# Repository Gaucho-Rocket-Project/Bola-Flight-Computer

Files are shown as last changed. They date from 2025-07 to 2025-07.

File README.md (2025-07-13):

# Bola Flight Computer  
*Lead Engineer: Ethan Scanlon & Jacob Ismael*  

> **Status:** Hardware‐only repository – PCB design files, footprints and production data for the first-generation Bola flight computer. Firmware lives in the separate [`bola`](https://github.com/Gaucho-Rocket-Project/bola) repo.

## Overview
Bola is an open-source, miniature flight computer for experimental rockets.  
It is built around an **ESP32-S3** microcontroller and pairs a 9-DoF IMU with a high-resolution barometer to provide real-time state estimation, data-logging and telemetry in a single, compact PCB.  

The hardware in this repository powers the Gaucho Rocket Project’s “Bola” launch vehicle and is released to help other student teams accelerate their avionics development.

## Key Features
| Sub-system | Parts/Notes |
|---|---|
| MCU | Espressif **ESP32-S3** module, 240 MHz dual-core, Wi-Fi & Bluetooth LE|
| Inertial sensing | **ICM-20948** 9-axis IMU (gyro + accel + mag) |
| Altimetry | **BMP581** absolute barometer (32-bit FIFO, 5 Pa RMS) |
| Power | 2-stage regulation: **LD1117-5 V** & **SPX3819-3 V3** LDOs |
| Pyro outputs | Low-side MOSFETs (**DMN3023L-7**) for ejection charges |
| User feedback | JST-XH debug header |
| Connectors | **XT30UPB** main supply; screw terminals for igniters |
| Form factor | 4-layer, 50 × 80 mm PCB < 15 g bare |

## Schematic
Schematic

## PCB Layout
pcb

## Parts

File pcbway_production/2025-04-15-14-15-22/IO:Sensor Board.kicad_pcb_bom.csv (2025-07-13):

Designator | Quantity | Value | Footprint | Package | MPN | DNP | Mount_Type | Description | LCSC | Comment | MF | DESCRIPTION | PRICE | Check_prices | Price | PARTREV | SnapEDA_Link | MP | Availability | AVAILABILITY | Description_1 | SUPPLIER_PART_NUMBER | VALUE | SUPPLIER | FOOTPRINT | MANUFACTURER_PART_NUMBER | STANDARD | MANUFACTURER | MAXIMUM_PACKAGE_HEIGHT
C1, C11, C12, C13, C2, C3, C4, C5, C6 | 9 | 0.1uF | C_0805_2012Metric_Pad1.18x1.45mm_HandSolder |  |  |  | smt | Unpolarized capacitor | C28233
C10, C14, C7, C8 | 4 | 10uF | C_0805_2012Metric_Pad1.18x1.45mm_HandSolder |  |  |  | smt | Unpolarized capacitor | C28233
C15, C9 | 2 | 100uF | C_0805_2012Metric_Pad1.18x1.45mm_HandSolder |  |  |  | smt | Unpolarized capacitor | C28233
J1, J2, J5 | 3 | B3B-XH-A | CONN_B3B-XH-A_JST |  |  |  | tht
J3 | 1 | B6B-XH-A | JST_XH_B6B-XH-A_1x06_P2.50mm_Vertical |  |  |  | tht |  | C144397
J4 | 1 | B2B-XH-A | CONN_B2B-XH-A_JST |  |  |  | tht |  | C158012
JP1, JP2, JP3 | 3 | Jumper_2_Open | SolderJumper-2_P1.3mm_Open_RoundedPad1.0x1.5mm |  |  |  | tht | Jumper, 2-pole, open
P1, P2, P3 | 3 | 282837-2 | CUI_TB002-500-02BE | None |  |  | tht |  |  | 282837-2 | TE Connectivity | TERMINAL BLOCK 3.5MM 2POS PCB | 0.28 USD | https://www.snapeda.com/parts/282837-2/TE+Connectivity+AMP+Connectors/view-part/?ref=eda | None | G3 | https://www.snapeda.com/parts/282837-2/TE+Connectivity+AMP+Connectors/view-part/?ref=snap | 282837-2 | In Stock | Good | Terminal Block Connector Wire Receptacle 2 5.08 mm 30-16 AWG Green 13.5 A 250 V | TE Connectivity 282837-2
Q1, Q2, Q3 | 3 | DMN3023L-7 | SOT96P240X100-3N | None |  |  | smt |  |  |  | Diodes Incorporated | MOSFET N-CH 30V 6.2A SOT23 |  | https://www.snapeda.com/parts/DMN3023L7/Diodes+Inc./view-part/?ref=eda | None |  | https://www.snapeda.com/parts/DMN3023L7/Diodes+Inc./view-part/?ref=snap | DMN3023L7 | In Stock |  | N-Channel 30 V 6.2A (Ta) 900mW (Ta) Surface Mount SOT-23-3 | DMN3023L-7DICT-ND | DMN3023L-7 | Digikey | SOT23 | DMN3023L-7
R1, R3, R5 | 3 | 1k | R_0805_2012Metric_Pad1.20x1.40mm_HandSolder | None |  |  | smt |  |  | 8-2176243-2 | TE Connectivity |  |  | https://www.snapeda.com/parts/8-2176243-2/TE+Connectivity+AMP+Connectors/view-part/?ref=eda | None |  | https://www.snapeda.com/parts/8-2176243-2/TE+Connectivity+AMP+Connectors/view-part/?ref=snap | 8-2176243-2 | In Stock |  | CRGS0603 Anti-Surge Resistor 5% 5M6
R2, R4, R6 | 3 | 470 | R_0805_2012Metric_Pad1.20x1.40mm_HandSolder | None |  |  | smt |  |  | 8-2176243-2 | TE Connectivity |  |  | https://www.snapeda.com/parts/8-2176243-2/TE+Connectivity+AMP+Connectors/view-part/?ref=eda | None |  | https://www.snapeda.com/parts/8-2176243-2/TE+Connectivity+AMP+Connectors/view-part/?ref=snap | 8-2176243-2 | In Stock |  | CRGS0603 Anti-Surge Resistor 5% 5M6
U1 | 1 | BMP581 | QFN10_BMP581_BOS |  |  |  | smt |  | C5362283
U10, U8 | 2 | XT30UPB-M | XT30UPB-M | None |  |  | tht |  |  |  | amass |  |  | https://www.snapeda.com/parts/XT30UPB-M/AMASS/view-part/?ref=eda | None |  | https://www.snapeda.com/parts/XT30UPB-M/AMASS/view-part/?ref=snap | XT30UPB-M | Not in stock |  | Socket; DC supply; XT30; male; PIN: 2; on PCBs; THT; yellow; 15A; 500V
U2 | 1 | DEVKIT_V1_ESP32-WROOM-32 | MODULE_DEVKIT_V1_ESP32-WROOM-32 | Package |  |  | tht |  |  |  | Espressif Systems |  |  | https://www.snapeda.com/parts/DEVKIT%20V1%20ESP32-WROOM-32/Espressif+Systems/view-part/?ref=eda | None | N/A | https://www.snapeda.com/parts/DEVKIT%20V1%20ESP32-WROOM-32/Espressif+Systems/view-part/?ref=snap | DEVKIT V1 ESP32-WROOM-32 | Not in stock |  | WROOM-32 Development Board ESP32 ESP-32S WiFi Bluetooth Dev Module |  |  |  |  |  | Manufacturer Recommendations | Espressif Systems
U3 | 1 | TPS79333-EP | SOT-23-5 |  |  |  | smt | 200mA UltraLow-Noise, High-Precision, Fast RF, Low Drop-out Voltage Regulator, Fixed Output 3.3V, SOT-23 | C9840
U4 | 1 | ICM-20948 | QFN24_3X3X0P9_IVS |  |  |  | smt |  | C726001
U5 | 1 | TPS79318-EP | SOT-23-5 |  |  |  | smt | 200mA UltraLow-Noise, High-Precision, Fast RF, Low Drop-out Voltage Regulator, Fixed Output 1.8V, SOT-23 | C7102
U7, U9 | 2 | LD1117S50CTR | LD1117S50CTR | SOT-223 STMicroelectronics |  |  | smt |  |  |  | STMicroelectronics |  |  | https://www.snapeda.com/parts/LD1117S50CTR/STMicroelectronics/view-part/?ref=eda | None | 37 | https://www.snapeda.com/parts/LD1117S50CTR/STMicroelectronics/view-part/?ref=snap | LD1117S50CTR | In Stock |  | Linear Voltage Regulator IC Positive Fixed 1 Output 800mA SOT-223 |  |  |  |  |  | IPC 7351B | STMicroelectronics | 1.8 mm

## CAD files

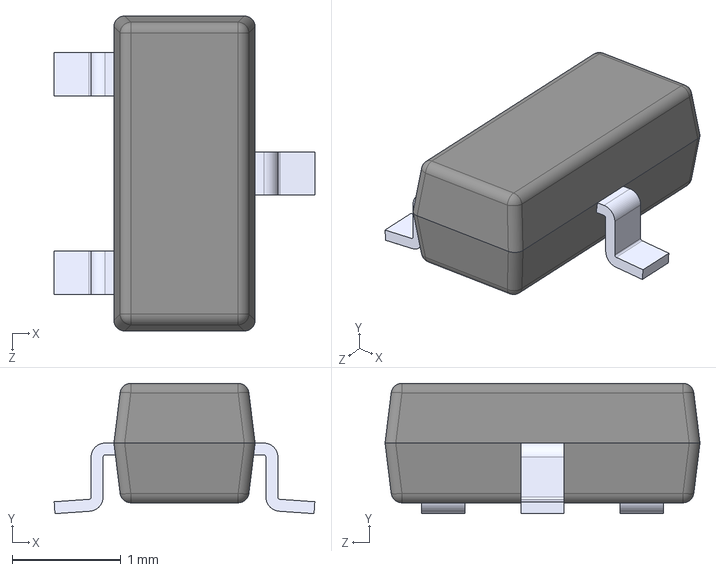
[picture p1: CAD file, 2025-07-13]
DMN3023L-7/DMN3023L-7.step
2.40 x 1.20 x 2.90 mm

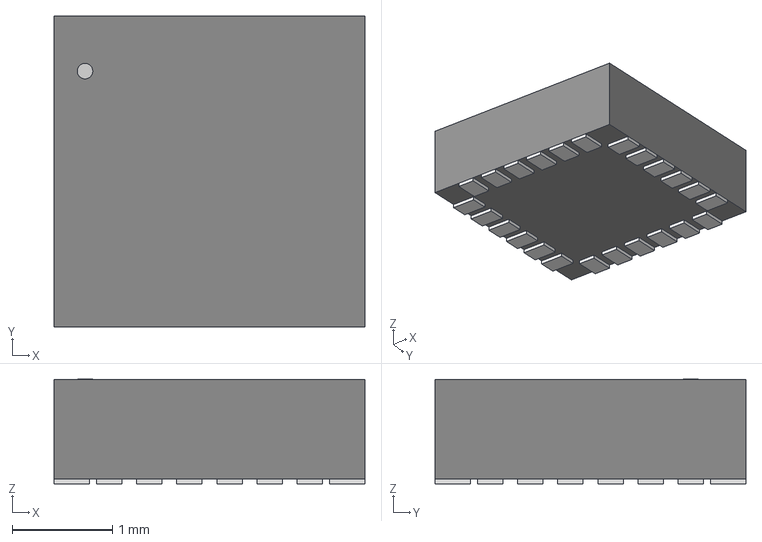
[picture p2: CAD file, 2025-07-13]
ICM-20948/QFN24_3X3X0P9_IVS.step
3.10 x 3.10 x 1.04 mm

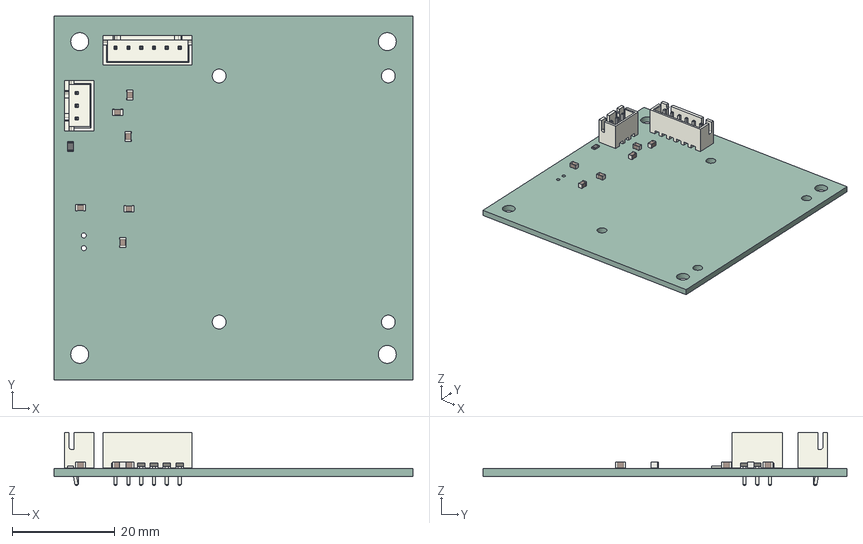
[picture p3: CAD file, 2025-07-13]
IO:Sensor Board.step
70.0 x 71.0 x 10.4 mm
JST_B3B_XH_A
C_0805_2012Metric x 6
R_0805_2012Metric
JST_B6B_XH_A
IO:Sensor Board_PCB

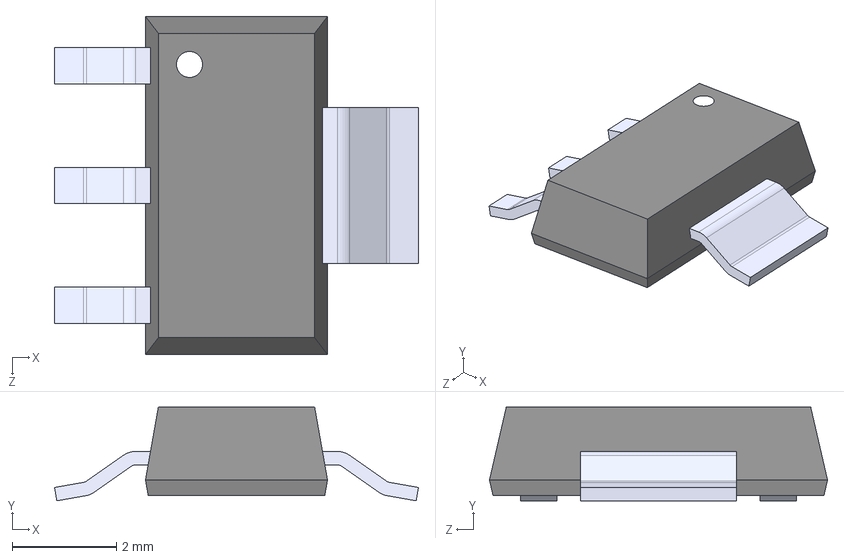
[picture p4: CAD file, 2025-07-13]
LD1117S50CTR/LD1117S50CTR.step
7.00 x 1.80 x 6.50 mm

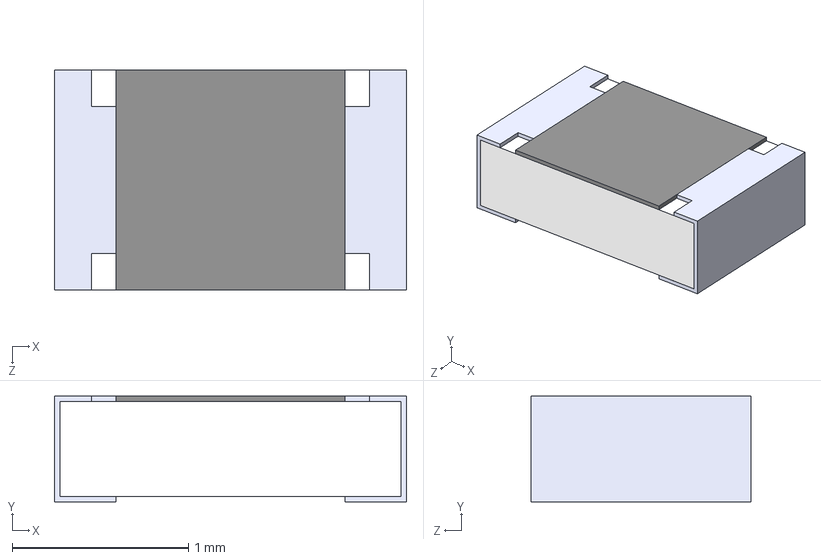
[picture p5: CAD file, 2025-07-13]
RC0805FR-071K5L/RC0805FR-071K5L.step
2.00 x 0.6 x 1.25 mm

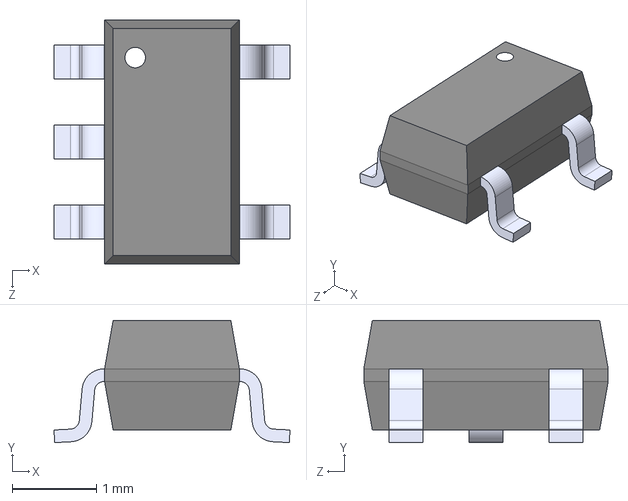
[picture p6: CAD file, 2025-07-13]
SPX3819/SPX 3819/SPX3819.step
2.80 x 1.45 x 2.90 mm

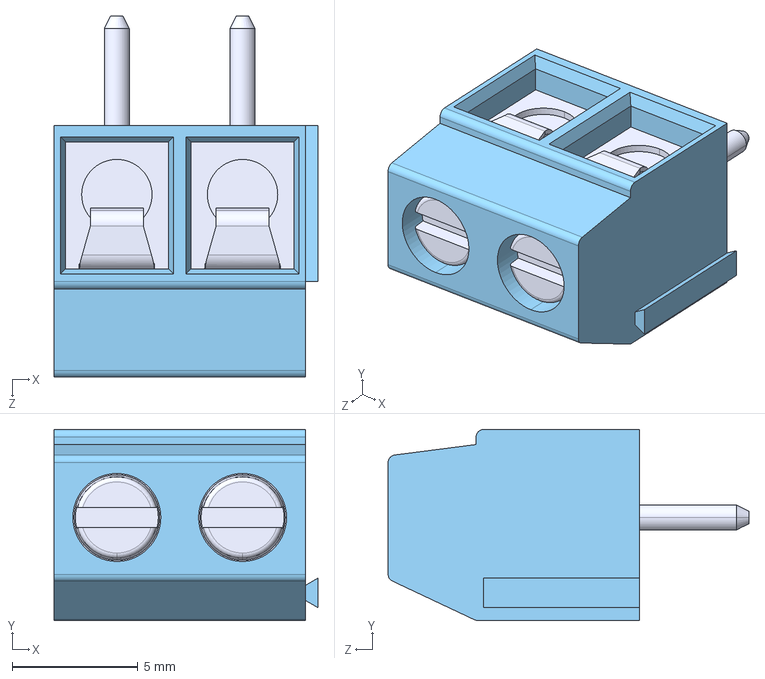
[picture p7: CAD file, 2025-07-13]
TB002-500-02BE/TB002-500-02BE.step
10.5 x 7.60 x 14.4 mm

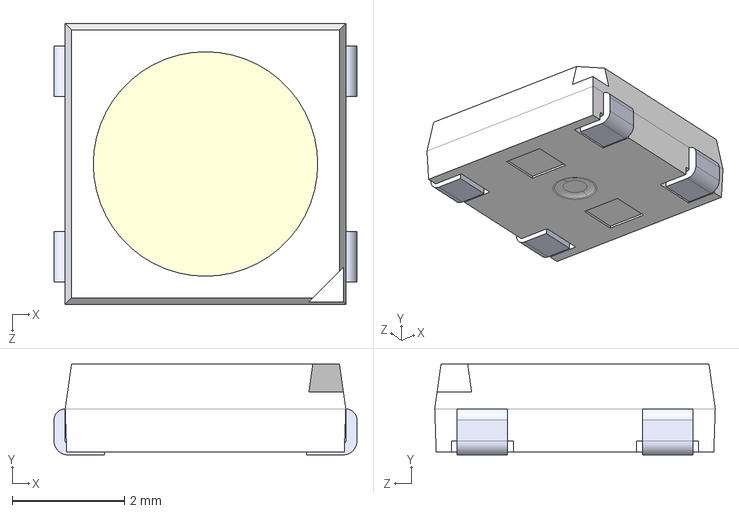
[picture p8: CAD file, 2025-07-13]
WS2812B/WS2812B.step
5.40 x 1.62 x 5.00 mm

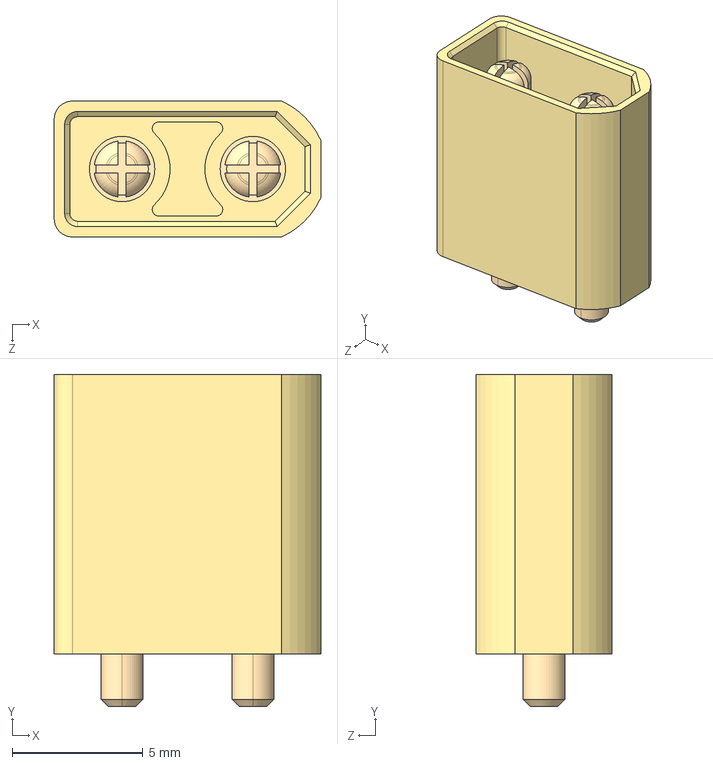
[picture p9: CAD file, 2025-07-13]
XT30UPB-M/XT30UPB-M.step
10.2 x 12.7 x 5.20 mm

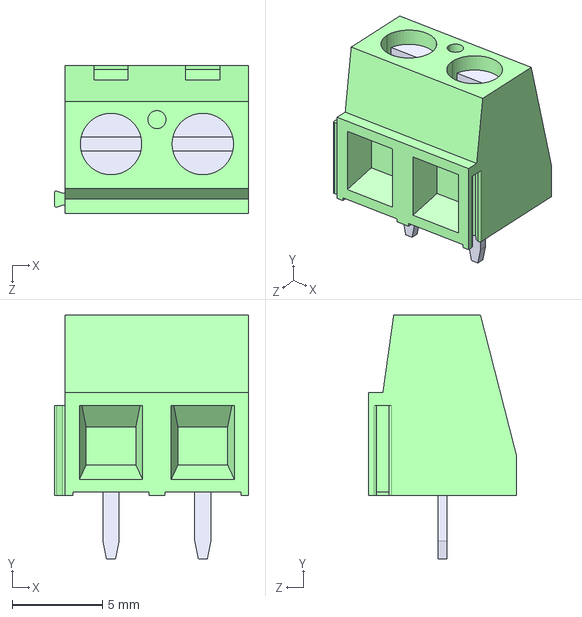
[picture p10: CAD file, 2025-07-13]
Screwterm/282837-2.step
10.8 x 13.5 x 8.20 mm

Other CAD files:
SensorBoard.step

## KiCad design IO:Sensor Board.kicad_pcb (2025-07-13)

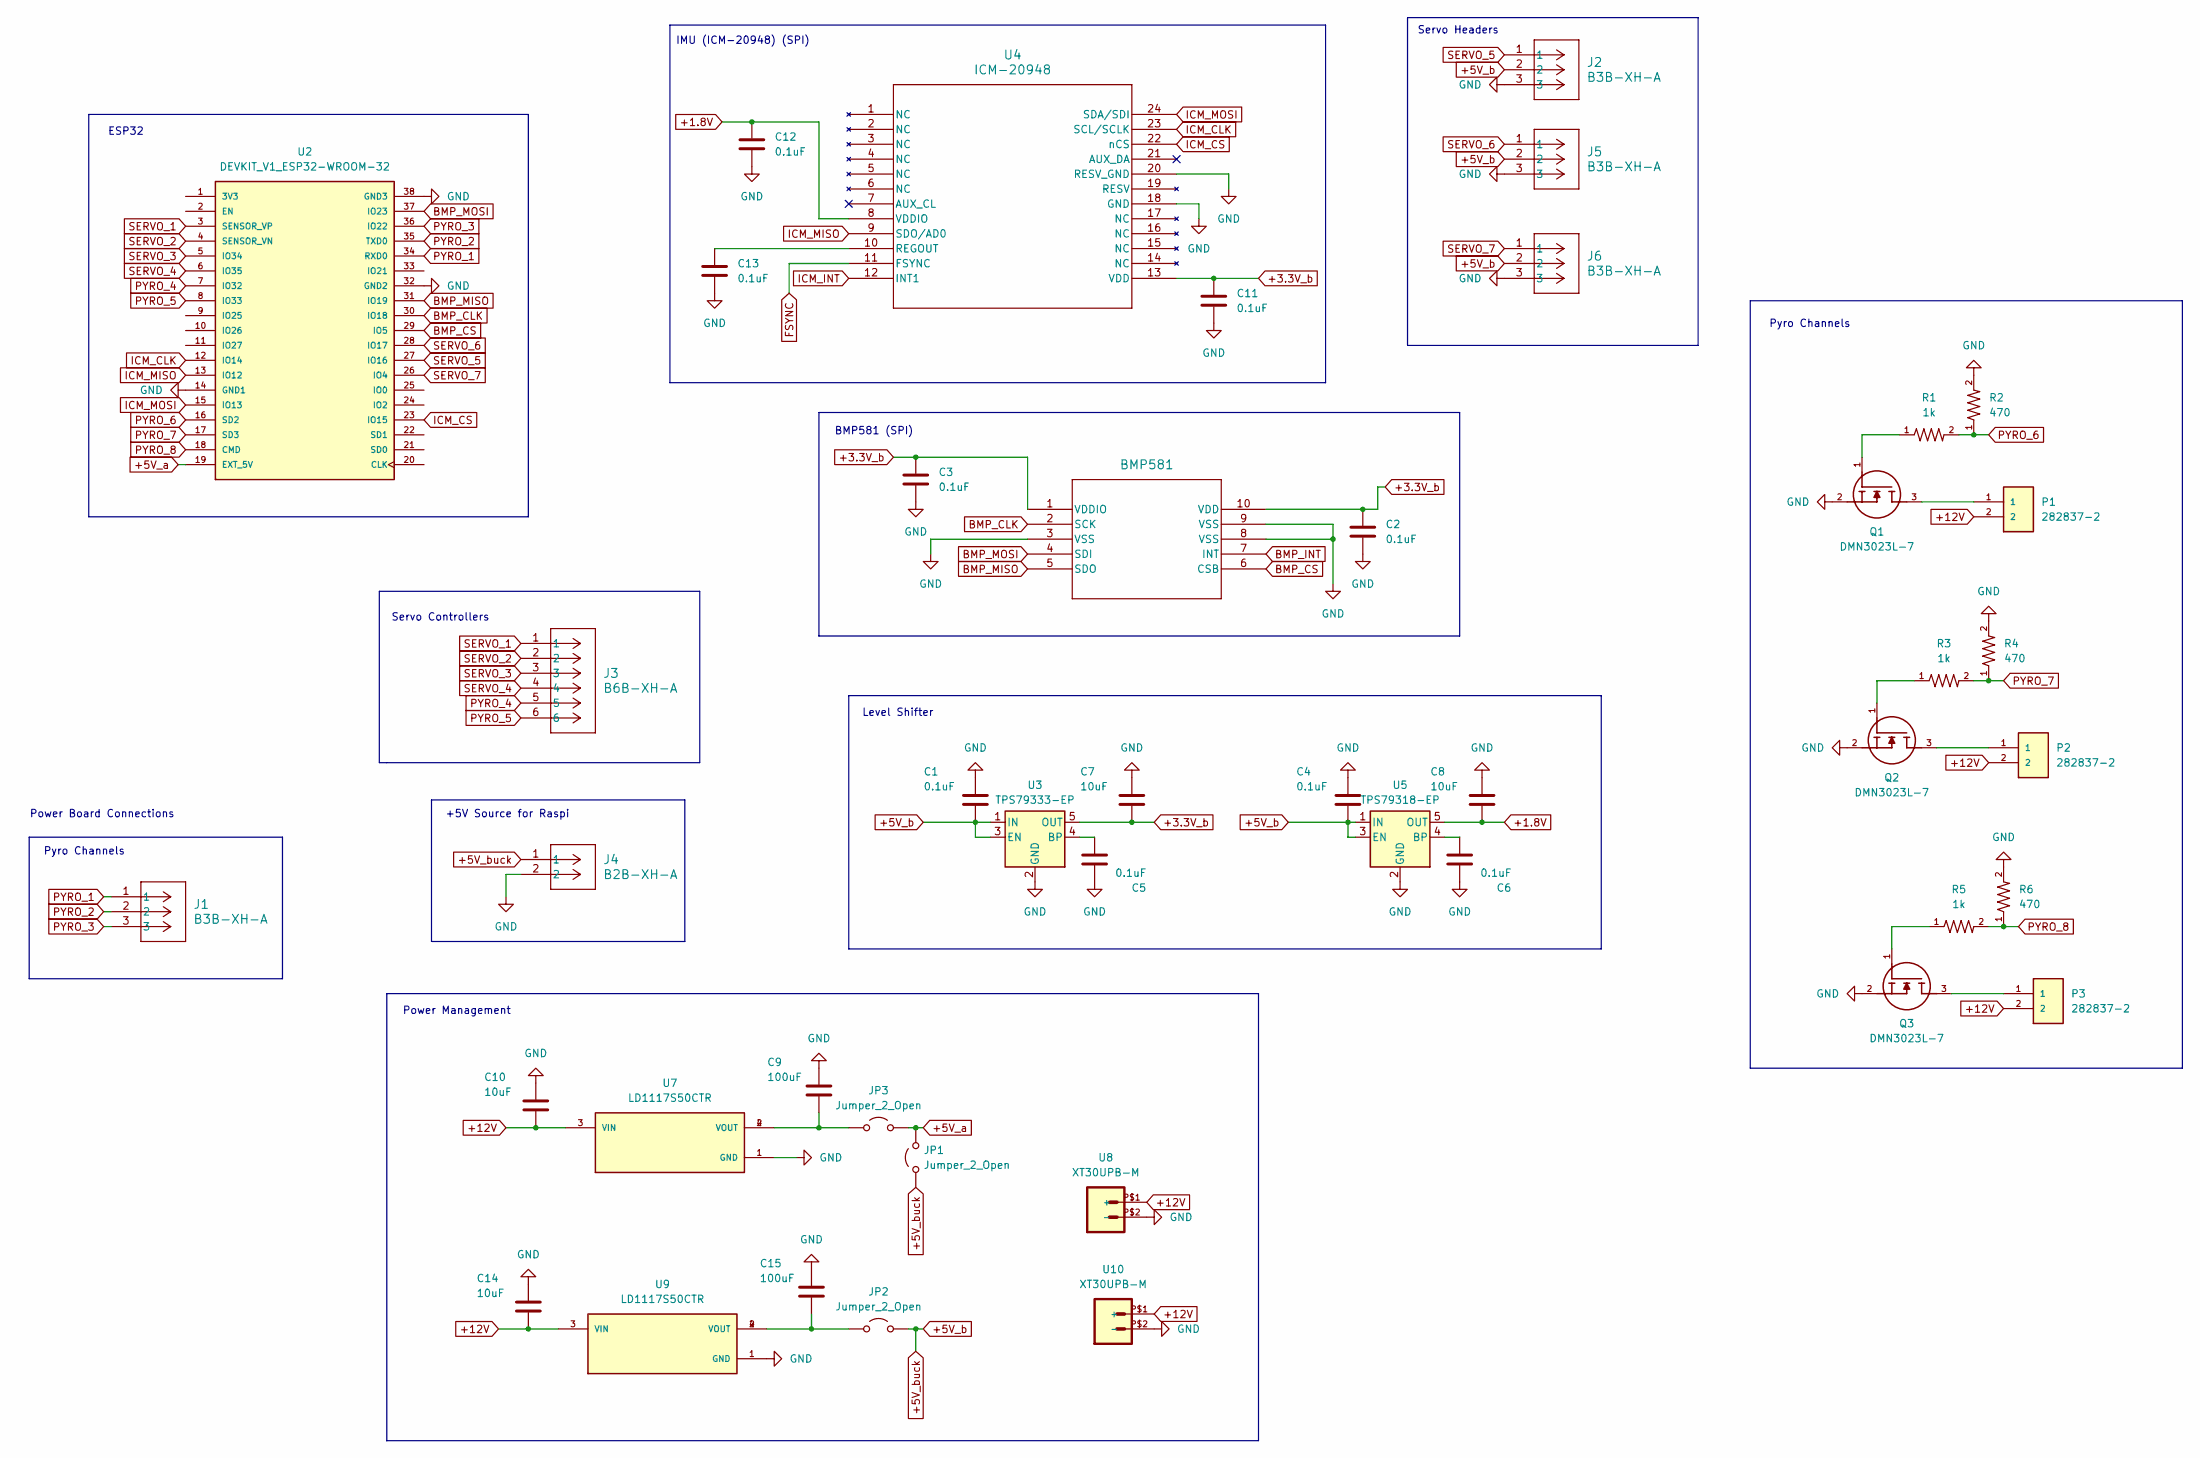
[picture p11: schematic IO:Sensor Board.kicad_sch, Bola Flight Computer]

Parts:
C1, C2, C3, C4, C5, C6, C11, C12, C13: 0.1uF; C_0805_2012Metric_Pad1.18x1.45mm_HandSolder
C7, C8, C10, C14: 10uF; C_0805_2012Metric_Pad1.18x1.45mm_HandSolder
C9, C15: 100uF; C_0805_2012Metric_Pad1.18x1.45mm_HandSolder
J1, J2, J5, J6: B3B-XH-A; CONN_B3B-XH-A_JST
J3: B6B-XH-A; JST_XH_B6B-XH-A_1x06_P2.50mm_Vertical
J4: B2B-XH-A; CONN_B2B-XH-A_JST
JP1, JP2, JP3: Jumper_2_Open; SolderJumper-2_P1.3mm_Open_RoundedPad1.0x1.5mm
P1, P2, P3: 282837-2; CUI_TB002-500-02BE; PARTREV G3
Q1, Q2, Q3: DMN3023L-7; SOT96P240X100-3N; MANUFACTURER_PART_NUMBER DMN3023L-7
R1, R3, R5: 1k; R_0805_2012Metric_Pad1.20x1.40mm_HandSolder
R2, R4, R6: 470; R_0805_2012Metric_Pad1.20x1.40mm_HandSolder
U1: BMP581; QFN10_BMP581_BOS
U2: DEVKIT_V1_ESP32-WROOM-32; MODULE_DEVKIT_V1_ESP32-WROOM-32; PARTREV N/A
U3: TPS79333-EP; SOT-23-5
U4: ICM-20948; QFN24_3X3X0P9_IVS
U5: TPS79318-EP; SOT-23-5
U7, U9: LD1117S50CTR; PARTREV 37
U8, U10: XT30UPB-M

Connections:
+1.8V: C8.2, C12.1, U4.8 (VDDIO), U5.5 (OUT)
+3.3V_b: C2.1, C3.1, C7.2, C11.1, U1.1 (VDDIO), U1.10 (VDD), U3.5 (OUT), U4.13 (VDD)
+5V_a: JP1.2 (B), JP3.2 (B), U2.19 (EXT_5V)
+5V_b: C1.2, C4.2, J2.2, J4.1, J5.2, J6.2, JP1.1 (A), JP2.2 (B), U3.1 (IN), U3.3 (EN), U5.1 (IN), U5.3 (EN)
+12V: C10.2, C14.2, P1.2, P2.2, P3.2, U7.3 (VIN), U8.P$1 (+), U9.3 (VIN), U10.P$1 (+)
BMP_CLK: U1.2 (SCK), U2.30 (IO18)
BMP_CS: U1.6 (CSB), U2.29 (IO5)
BMP_INT: U1.7 (INT)
BMP_MISO: U1.5 (SDO), U2.31 (IO19)
BMP_MOSI: U1.4 (SDI), U2.37 (IO23)
FSYNC: U4.11 (FSYNC)
GND: C1.1, C2.2, C3.2, C4.1, C5.1, C6.1, C7.1, C8.1, C9.1, C10.1, C11.2, C12.2, C13.2, C14.1, C15.1, J2.3, J4.2, J5.3, J6.3, Q1.2, Q2.2, Q3.2, R2.2, R4.2, R6.2, U1.3 (VSS), U1.8 (VSS), U1.9 (VSS), U2.14 (GND1), U2.32 (GND2), U2.38 (GND3), U3.2 (GND), U4.18 (GND), U4.20 (RESV_GND), U5.2 (GND), U7.1 (GND), U8.P$2 (-), U9.1 (GND), U10.P$2 (-)
ICM_CLK: U2.12 (IO14), U4.23 (SCL/SCLK)
ICM_CS: U2.23 (IO15), U4.22 (nCS)
ICM_INT: U4.12 (INT1)
ICM_MISO: U2.13 (IO12), U4.9 (SDO/AD0)
ICM_MOSI: U2.15 (IO13), U4.24 (SDA/SDI)
unnamed: C15.2, JP2.1 (A), U9.2 (VOUT), U9.4 (VOUT)
unnamed: C9.2, JP3.1 (A), U7.2 (VOUT), U7.4 (VOUT)
unnamed: P1.1, Q1.3
unnamed: P2.1, Q2.3
unnamed: P3.1, Q3.3
unnamed: Q1.1, R1.1
unnamed: Q2.1, R3.1
unnamed: Q3.1, R5.1
unnamed: C5.2, U3.4 (BP)
unnamed: C13.1, U4.10 (REGOUT)
unnamed: C6.2, U5.4 (BP)
PYRO_1: J1.1, U2.34 (RXD0)
PYRO_2: J1.2, U2.35 (TXD0)
PYRO_3: J1.3, U2.36 (IO22)
PYRO_4: J3.5, U2.7 (IO32)
PYRO_5: J3.6, U2.8 (IO33)
PYRO_6: R1.2, R2.1, U2.16 (SD2)
PYRO_7: R3.2, R4.1, U2.17 (SD3)
PYRO_8: R5.2, R6.1, U2.18 (CMD)
SERVO_1: J3.1, U2.3 (SENSOR_VP)
SERVO_2: J3.2, U2.4 (SENSOR_VN)
SERVO_3: J3.3, U2.5 (IO34)
SERVO_4: J3.4, U2.6 (IO35)
SERVO_5: J2.1, U2.27 (IO16)
SERVO_6: J5.1, U2.28 (IO17)
SERVO_7: J6.1, U2.26 (IO4)

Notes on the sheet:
Level Shifter
+5V Source for Raspi
ESP32
Pyro Channels
BMP581 (SPI)
Servo Headers
Power Management
IMU (ICM-20948) (SPI)
Power Board Connections
Servo Controllers

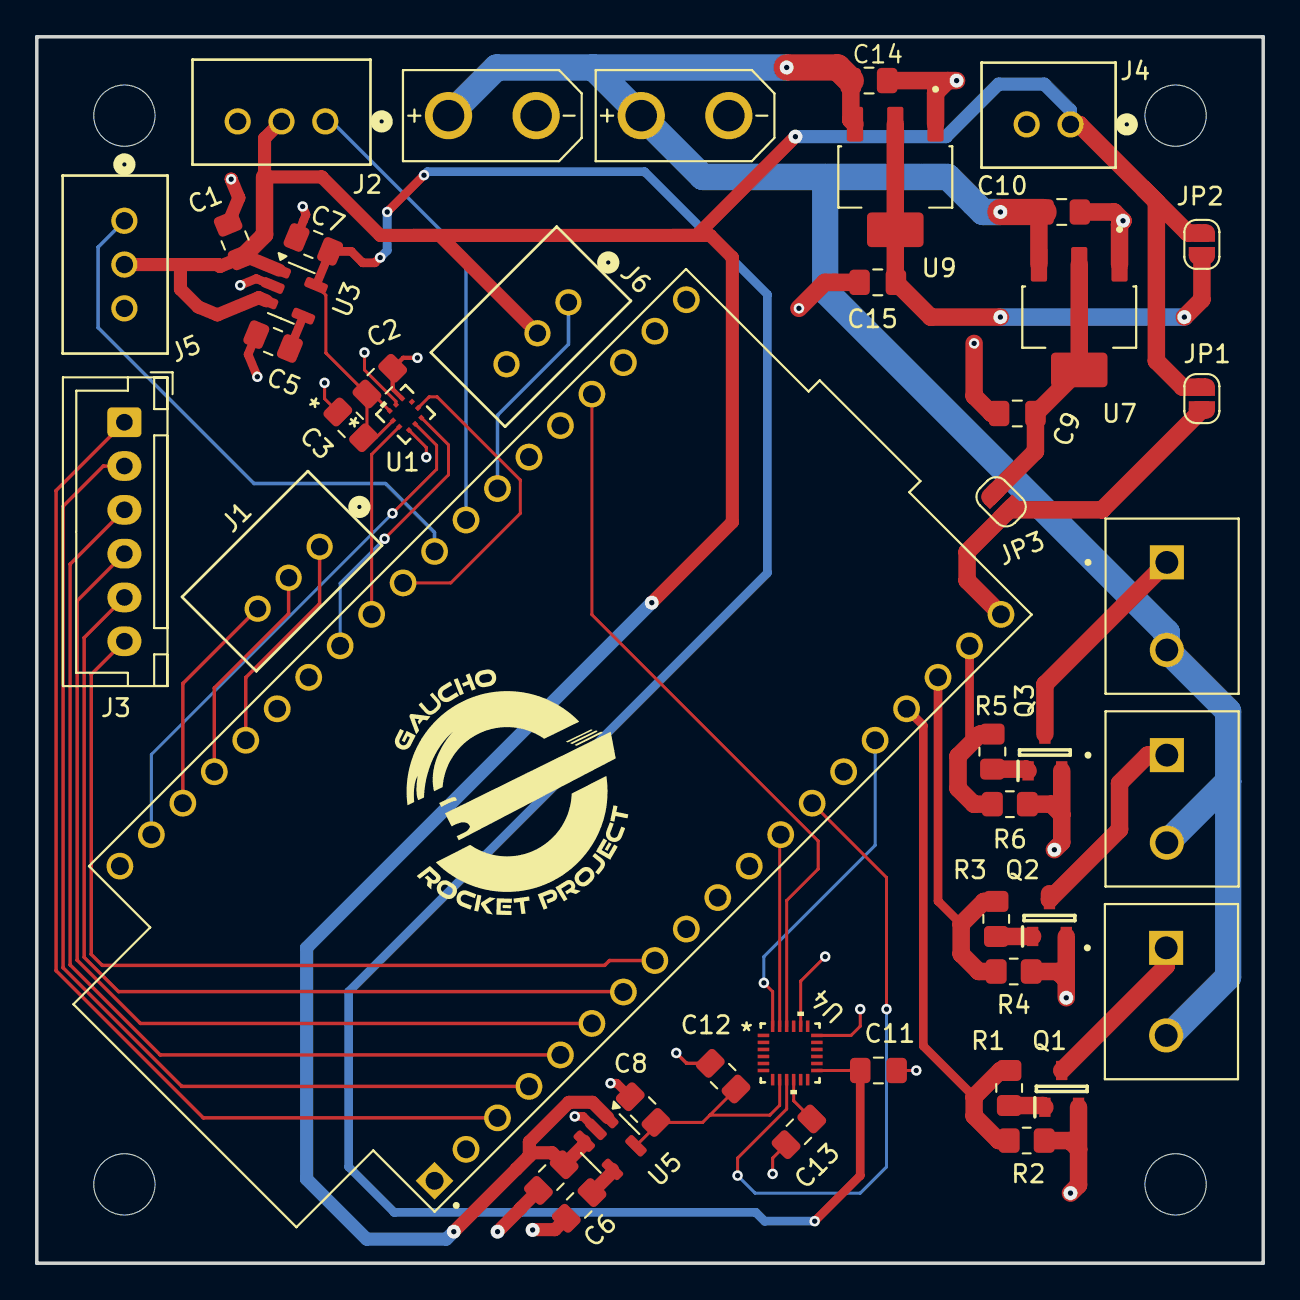
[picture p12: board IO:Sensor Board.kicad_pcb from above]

Board: 4 copper layers, 70.0 x 70.0 mm, 45 parts (0 on the bottom side), 40 nets.
